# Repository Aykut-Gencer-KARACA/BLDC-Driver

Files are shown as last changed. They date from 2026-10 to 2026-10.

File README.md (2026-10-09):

<div align="center">

BLDC ESC — STM32F405 + DRV8300 sensörsüz six-step motor sürücü

<br/>









<br/><br/>

**Sıfırdan tasarlanmış bir fırçasız DC (BLDC) motor sürücüsü.**<br/>
Hall sensörü olmadan, boştaki fazın back-EMF sıfır geçişini okuyarak rotor konumunu tahmin eder.

<br/>

<a href="assets/pcb-render.mp4">
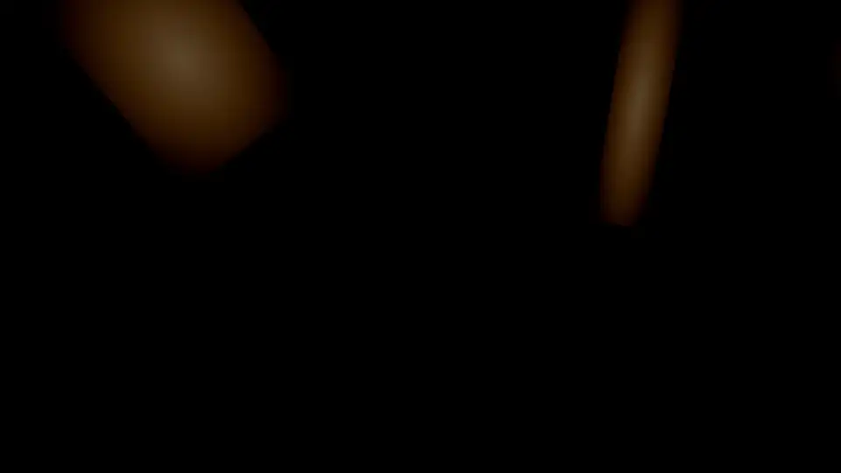
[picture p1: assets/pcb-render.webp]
PCB 3D render animasyonu
  
</a>

<sub>PCB'nin Blender'da hazırlanmış 3D render'ı · tam çözünürlüklü video için görsele tıklayın</sub>

</div>

<!--
  ────────────────────────────────────────────────────────────────────────────
  OYNATILABİLİR VİDEO (isteğe bağlı)
  GitHub, repodaki .mp4 dosyalarını README içinde oynatıcı olarak GÖSTERMEZ.
  Oynatıcı istiyorsanız:
    1) GitHub'da README.md'yi web editöründe açın (kalem simgesi).
    2) assets/pcb-render.mp4 dosyasını editöre sürükleyip bırakın.
    3) Oluşan https://github.com/user-attachments/assets/... satırını
       aşağıdaki "VIDEO_LINKI_BURAYA" satırının yerine koyun (tek başına, kendi satırında).
    4) Bu yorum bloğunu silebilirsiniz.
  ────────────────────────────────────────────────────────────────────────────
-->

<!-- VIDEO_LINKI_BURAYA -->



## İçindekiler

- [Genel bakış](#-genel-bakış)
- [Öne çıkanlar](#-öne-çıkanlar)
- [Sistem mimarisi](#-sistem-mimarisi)
- [Six-step komütasyon](#-six-step-komütasyon)
- [Donanım](#-donanım)
- [Tasarım hesapları](#-tasarım-hesapları)
- [Pin haritası](#-pin-haritası)
- [PCB](#-pcb)
- [Malzeme listesi](#-malzeme-listesi)
- [Depo yapısı](#-depo-yapısı)

## ◆ Genel bakış

Bu proje, bir **A2212 1000 KV** fırçasız motoru **3S LiPo** batarya ile sürmek için tasarlanmış bir ESC'dir (Electronic Speed Controller). Kart; güç girişi koruması, iki ayrı regülatör, 3 fazlı MOSFET köprüsü, faz başına bağımsız akım ölçümü, back-EMF algılama ve bir **STM32F405** mikrodenetleyiciyi tek bir PCB üzerinde topluyor.

Tasarımdaki her değer bir hesaba dayanıyor: MOSFET seçiminden bootstrap kondansatörüne, dead-time'dan ferrit bead bastırma oranına kadar kararların gerekçesi [Tasarım hesapları](#-tasarım-hesapları) bölümünde; tüm türetimler adım adım [Hesaplama Notları](Hesaplama%20Notları.pdf) dosyasında.

| Özellik | Değer |
|---|---|
| **Kontrol yöntemi** | Sensörsüz six-step (trapezoidal), back-EMF sıfır geçişi |
| **Giriş gerilimi** | 3S LiPo · 11.1 V nominal · 12.6 V maksimum |
| **Faz akımı** | 10 A sürekli · 12 A tepe (tasarım hedefi) |
| **Anahtarlama** | 30 kHz, center-aligned PWM, ~11.4 bit duty çözünürlüğü |
| **Dead-time** | 2 katman: TIM1 DTG ≈ 1 µs + DRV8300 sabit ≈ 215 ns (tipik) |
| **Akım ölçümü** | 3 × low-side şönt (10 mΩ) + 3 × INA180A1 (20 V/V), eşzamanlı örnekleme |
| **Hız ayarı** | Panel montaj 10 kΩ potansiyometre |
| **Programlama** | SWD (ST-Link V2) |

## ◆ Öne çıkanlar

<table>
<tr>
<td width="50%" valign="top">

**Katmanlı giriş koruması**<br/>
TVS diyot (SMBJ20A, 32.4 V clamp), 20 A SMD sigorta ve P-kanal ters polarite MOSFET. Hot-plug ve anahtarlama kaynaklı gerilim darbelerine karşı koruma.

</td>
<td width="50%" valign="top">

**Faz başına eşzamanlı akım ölçümü**<br/>
Üç şönt akımı üç ayrı ADC'ye dağıtıldı (ADC1/2/3) ve her birinde **Rank 1** kanalı. TIM1 CH4 tetiklediği anda üç faz aynı anda örnekleniyor, fazlar arası zaman kayması yok.

</td>
</tr>
<tr>
<td valign="top">

**Isıl hesabı yapılmış MOSFET seçimi**<br/>
DON100N04 (40 V, < 3.5 mΩ, **Q<sub>g</sub> ≈ 40 nC** @ 10 V). 10.5 A'de MOSFET başına ≈ 0.39 W (25 °C); sıcakken (4.46 mΩ) ≈ 0.49 W ve 40 °C ortamda T<sub>J</sub> ≈ 65 °C. Bu kartta tek MOSFET'in ısıl sınırı ≈ 22 A.

</td>
<td valign="top">

**Temiz analog besleme**<br/>
VDDA hattı ferrit bead + 100 nF + 1 µF ile buck ripple'ından ayrıldı. 500 kHz'de tahmini **30–60 kat (%97–98) bastırma**. ADC referansı ve CSA beslemesi aynı hattan: ölçüm oransal (ratiometric).

</td>
</tr>
<tr>
<td valign="top">

**Hesaplanmış bootstrap**<br/>
C<sub>BOOT,min</sub> ≈ 47 nF (TI'ın 1 V dalgalanma kuralı), seçilen 100 nF ile **~2× pay** ve ≈ 0.47 V dalgalanma. Üst kol kesintisiz açık kalamayacağı için %100 duty kullanılmıyor.

</td>
<td valign="top">

**Sanal nötr ile back-EMF algılama**<br/>
Faz başına 20 kΩ / 4.99 kΩ bölücü 12.6 V'u ≈ 2.52 V'a indiriyor; 3 × 20 kΩ + 1.65 kΩ'luk sanal nötr aynı ölçekte (sapma ≈ %0.7). Boştaki fazın nötrü kestiği an sıfır geçişi.

</td>
</tr>
</table>

## ◆ Sistem mimarisi

<p align="center">
  Sistem mimarisi blok diyagramı
</p>

Güç yolu soldan sağa akıyor: batarya, sırasıyla sigorta (F1), TVS diyodu (D1) ve ters polarite MOSFET'inden (Q7) geçip `V_BUS` barasına ulaşıyor. Bu baradan üç kol ayrılıyor:

- **TPS54202 buck** → 3.3 V (MCU, CSA'lar, potansiyometre) · 500 kHz senkron
- **BA00BC0WFP LDO** → 8 V GVDD (DRV8300 gate sürme beslemesi) · ≈ 5 mA tipik, en fazla ≈ 11 mA yük
- **3 faz köprü** → motor fazları A / B / C

STM32, TIM1'in 6 tamamlayıcı PWM çıkışıyla DRV8300'ü sürüyor; DRV8300 de bootstrap üzerinden üst kol N-kanal MOSFET'lerin gate'lerini bara geriliminin üstüne taşıyor.

## ◆ Six-step komütasyon

<p align="center">
  Six-step komütasyon animasyonu
</p>

Her elektriksel periyot altı adıma bölünüyor. Her adımda **iki faz aktif** (biri üst koldan PWM'leniyor, diğeri alt koldan sürekli iletimde), **üçüncü faz boşta** kalıyor. Boştaki fazın back-EMF'i sanal nötr seviyesini kestiği anda (sıfır geçişi) rotorun konumu biliniyor ve bir sonraki adıma geçiş zamanlanıyor.

| Adım | 1 | 2 | 3 | 4 | 5 | 6 |
|:--|:-:|:-:|:-:|:-:|:-:|:-:|
| **Üst kol (PWM)** | A | A | B | B | C | C |
| **Alt kol (açık)** | B | C | C | A | A | B |
| **Boşta (BEMF ölçümü)** | C | B | A | C | B | A |

> [!NOTE]
> Motor dururken back-EMF olmadığı için sensörsüz kontrolde **açık döngü başlatma** (open-loop ramp) gerekiyor. Motor yeterli hıza ulaşıp BEMF okunabilir hale geldiğinde kapalı döngüye geçiliyor.

## ◆ Donanım

<details open>
<summary><b>Güç katı</b></summary>
<br/>

| Blok | Parça | Not |
|---|---|---|
| Yarım köprü MOSFET'leri | 6 × **DON100N04** (DFN-8) | 40 V · < 3.5 mΩ · Q<sub>g</sub> ≈ 40 nC · gövde diyodu yeterli, harici Schottky yok |
| Gate dirençleri | 6 × 15 Ω | TI referans tasarımı ve bağımsız hesapla doğrulandı |
| Gate pull-down | 6 × 10 kΩ | Self turn-on koruması |
| Faz kondansatörleri | Faz başına 100 µF + 1 µF + 100 nF | Bulk + decoupling |

</details>

<details>
<summary><b>Gate sürücü — DRV8300</b></summary>
<br/>

- DT pini boşta (ya da GND'de): dahili dead-time ≈ 215 ns (tipik, datasheet)
- Bootstrap: 100 nF, entegre bootstrap diyodu
- GVDD: 8 V LDO çıkışı
- nFAULT çıkışı yok → donanımsal aşırı akım kesmesi (BKIN) yok; akım, şönt + INA180 zinciriyle ölçülüyor

</details>

<details>
<summary><b>Akım ölçümü</b></summary>
<br/>

- 3 × **10 mΩ / 3 W** şönt (2512), alt kol altında (low-side)
- 3 × **INA180A1** (20 V/V) — 12 A'de 2.4 V çıkış
- Çıkışta 100 Ω + 22 nF RC filtre (f<sub>c</sub> ≈ 72 kHz)
- 12-bit ADC ile çözünürlük ≈ **4 mA / LSB**

</details>

<details>
<summary><b>Back-EMF algılama</b></summary>
<br/>

- Faz başına bölücü: 20 kΩ / 4.99 kΩ → 12.6 V faz geriliminde **≈ 2.52 V** ADC girişi
- Sanal nötr: 3 × 20 kΩ yıldız + 1.65 kΩ (R<sub>n</sub> = R<sub>alt</sub>/3) → faz bölücüleriyle aynı ölçek
- Tüm dirençler ±%1; ölçek sapması ≈ %0.7

</details>

<details>
<summary><b>Mikrodenetleyici — STM32F405RGT6</b></summary>
<br/>

- Cortex-M4F · 168 MHz · 1 MB Flash · 192 KB RAM · FPU
- 8 MHz HSE kristal, 2 × 30 pF yük kondansatörü (C<sub>L</sub> = 20 pF)
- VCAP1/2: 2 × 2.2 µF X5R
- 4 × VDD'ye ayrı 100 nF, VBAT → 3.3 V + 100 nF
- NRST: 100 nF + tact switch · BOOT0: 10 kΩ ile GND
- SWD: 4 pinlik 2.54 mm header (3.3 V, SWDIO, SWCLK, GND)

</details>

<details>
<summary><b>Göstergeler (LED)</b></summary>
<br/>

| LED | Görev | Sürüş | Akım |
|---|---|---|---|
| LED1 | Güç göstergesi | 3.3 V → R38 (200 Ω) → LED1 → GND | ≈ 6.5 mA |
| LED2 | SWD aktivite göstergesi | 3.3 V → R39 (200 Ω) → LED2 → Q8 (MMBT5551, low-side) · baz SWCLK'ten R40 (10 kΩ) ile | ≈ 6.5 mA |

- LED2, debugger bağlıyken SWCLK üzerindeki trafikle yanıp söner; MCU pini harcamaz.
- Q8'in baz akımı ≈ 0.26 mA — SWCLK hattını anlamlı ölçüde yüklemez.

</details>

## ◆ Tasarım hesapları

<details>
<summary><b>MOSFET seçimi</b></summary>
<br/>

$$V_{DS} \geq 2 \times V_{\text{bara,max}} = 2 \times 12.6\text{ V} = 25.2\text{ V} \quad\Rightarrow\quad 40\text{ V sınıfı}$$

$$I_D \geq 3 \times I_{\text{çalışma}} = 3 \times 10\text{ A} = 30\text{ A} \quad\Rightarrow\quad \text{DON100N04: 100 A}$$

İletim kaybı, 25 °C'de $R_{DS(on)} \leq 3.5\text{ m}\Omega$ ile:

$$P = I^2 \times R_{DS(on)} = 10.5^2 \times 0.0035 \approx 0.39\text{ W}$$

Asıl karar ısıl hesapla verilir. Sıcakken (150 °C) direnç ≈ 4.46 mΩ, R<sub>θJA</sub> = 50 °C/W ve T<sub>A</sub> = 40 °C ile:

$$P = 10.5^2 \times 0.00446 \approx 0.49\text{ W} \quad\Rightarrow\quad T_J = T_A + P \times R_{\theta JA} = 40 + 0.49 \times 50 \approx 65\text{ °C}$$

$$I_{max} = \sqrt{\frac{(150 - 40)/50}{0.00446}} = \sqrt{\frac{2.2\text{ W}}{0.00446\ \Omega}} \approx 22\text{ A}$$

Yani bu kartta tek bir MOSFET'in sürekli taşıyabileceği akım datasheet'teki 100 A değil, yaklaşık 22 A'dir; 10.5 A çalışma noktası bunun çok altındadır.

</details>

<details>
<summary><b>Bootstrap kondansatörü</b></summary>
<br/>

$$\Delta V_{BST} = V_{GVDD} - V_{BOOTD} - V_{BSTUV} = 8 - 0.85 - 4.5 = 2.65\text{ V}$$

$$Q_{tot} = Q_g + \frac{I_{LBS,TRAN}}{f_{sw}} = 40\text{ nC} + \frac{220\ \mu\text{A}}{30\text{ kHz}} \approx 47\text{ nC}$$

TI, kondansatör üzerindeki çevrim başına dalgalanmanın 1 V'u geçmemesini öneriyor:

$$C_{BOOT,min} = \frac{Q_{tot}}{1\text{ V}} \approx 47\text{ nF} \quad\Rightarrow\quad 100\text{ nF seçildi (yaklaşık 2 kat pay)}$$

100 nF ile dalgalanma $47\text{ nC} / 100\text{ nF} \approx 0.47\text{ V}$, yani 2.65 V'luk sınırın çok altında. GVDD tarafında kural $C_{GVDD} \geq 10 \times C_{BOOT} = 1\ \mu\text{F}$; datasheet GVDD pininde ayrıca en az 10 µF istiyor (C43 = 10 µF, C40 = 1 µF, C42 = 100 nF).

Üst kolun kesintisiz açık kalabileceği süre, 150 µA'lik statik sızıntıyla $2.65\text{ V} \times 100\text{ nF} / 150\ \mu\text{A} \approx 1.8\text{ ms}$ (≈ 53 PWM periyodu). Bu yüzden duty %100'e çıkarılmamalı ve motor başlamadan önce alt kollar açılarak bootstrap kondansatörleri şarj edilmeli.

</details>

<details>
<summary><b>Gate direnci ve anahtarlama süresi</b></summary>
<br/>

$$I_{\text{tepe}} \approx \frac{V_{GVDD}}{R_g} = \frac{8\text{ V}}{15\ \Omega} \approx 0.5\text{ A}$$

Sürücünün kendi iç direnci eklendiği için gerçek tepe akım bunun biraz altında kalır ve DRV8300'ün 0.75 A'lik (tipik) açma akımı sınırının içindedir. 15 Ω daha yumuşak anahtarlama (düşük di/dt, düşük aşım) ile daha hızlı anahtarlama arasında bir dengedir.

Sürücünün işi: 40 nC'luk gate'i bir GPIO'nun 25 mA'iyle doldurmak $t \approx Q_g / I = 40\text{ nC} / 25\text{ mA} \approx 1.6\ \mu\text{s}$ sürerdi; DRV8300'ün 0.75 A'iyle aynı süre ≈ 53 ns'dir.

</details>

<details>
<summary><b>PWM çözünürlüğü</b></summary>
<br/>

Center-aligned modda sayaç yukarı-aşağı saydığı için:

$$ARR = \frac{f_{timer}}{2 \times f_{PWM}} = \frac{168\text{ MHz}}{2 \times 30\text{ kHz}} = 2800 \;\;(\approx 11.4\text{ bit})$$

</details>

<details>
<summary><b>GVDD akım bütçesi ve LDO</b></summary>
<br/>

Six-step'te her an yalnızca PWM uygulanan koldaki iki MOSFET anahtarlanır:

$$I_{\text{gate}} = 2 \times Q_g \times f_{sw} = 2 \times 40\text{ nC} \times 30\text{ kHz} = 2.4\text{ mA}$$

(Altı MOSFET'in birden anahtarlandığı en kötü durumda 7.2 mA.) Üst kol gate yükü bootstrap kondansatöründen akar ama her çevrimde yine GVDD'den yeniden alınır, bu yüzden bütçeye dahildir.

| Kalem | Tipik | En fazla |
|---|---|---|
| DRV8300 kendi tüketimi | 0.83 mA | 1.4 mA |
| Gate'leri doldurmak | 2.4 mA | 7.2 mA |
| Bootstrap tüketimi (3 kanal) | 0.32 mA | 0.66 mA |
| Gate pull-down'lar (2 MOSFET iletimde, 8 V / 10 kΩ) | 1.6 mA | 1.6 mA |
| **Toplam** | **≈ 5.2 mA** | **≈ 10.9 mA** |

LDO çıkışı: $V_O = 1.25 \times \frac{30k + 162k}{30k} = 8\text{ V}$

LDO kaybı: $P = (V_{in} - V_{out}) \times I = (12.6 - 8) \times 5.2\text{ mA} \approx 24\text{ mW}$ (üst sınır: $4.6\text{ V} \times 10.9\text{ mA} \approx 50\text{ mW}$).

</details>

<details>
<summary><b>3.3 V buck regülatörü</b></summary>
<br/>

| Yük | Akım |
|---|---|
| STM32F405 (168 MHz) | ~150 mA |
| 3 × INA180 | 1 mA |
| LDO CTL pini | 0.13 mA |
| Potansiyometre | ~1 mA |
| LED'ler (LED1 + LED2, her biri ≈ 6.5 mA) | ~13 mA |
| **Toplam** | **~165 mA** → TPS54202 2 A (≈ 12× akım payı, 28 V / 12.6 V ≈ 2.2× gerilim payı) |

Buck yerine LDO kullanılsaydı kayıp $(12.6 - 3.3) \times 0.165 \approx 1.5\text{ W}$ olurdu; 8 V'luk LDO'da ise akım yalnızca birkaç mA olduğu için bu sorun yok.

$V_{OUT} = 0.596 \times \frac{100k + 22.1k}{22.1k} \approx 3.29\text{ V}$ · L = 10 µH · C<sub>OUT</sub> = 2 × 22 µF · 56 pF feedforward.

500 kHz anahtarlama frekansı CSA filtresinin kesim frekansından (≈ 72 kHz) ≈ 7 kat uzakta; filtre bu gürültüyü ≈ 7 kat (−17 dB) azaltır.

</details>

<details>
<summary><b>Akım ölçüm zinciri</b></summary>
<br/>

$$V_{out} = I \times R_{\text{şönt}} \times G = 12\text{ A} \times 10\text{ m}\Omega \times 20 = 2.4\text{ V}$$

$$1\text{ LSB} = \frac{3.3\text{ V}}{4096} \approx 0.806\text{ mV} \quad\Rightarrow\quad \approx 4\text{ mA / LSB}$$

Çıkış 3.3 V'ta doyduğu için ölçülebilecek en büyük akım $3.3\text{ V} / 0.2\text{ V/A} \approx 16.5\text{ A}$; bu değer çalışma akımının üstünde, 22 A'lik ısıl sınırın altındadır ve doymuş çıkış zaten aşırı akım demektir.

Şönt low-side'da olduğu için common-mode gerilim 0–120 mV aralığında (12 A'de 120 mV) kalıyor; high-side ölçümün yüksek common-mode salınımıyla uğraşmak gerekmiyor.

</details>

## ◆ Pin haritası

<table>
<tr>
<td valign="top">

**TIM1 → DRV8300**

| Kanal | Pin | Giriş |
|---|---|---|
| CH1 | PA8 | INHA |
| CH2 | PA9 | INHB |
| CH3 | PA10 | INHC |
| CH1N | PB13 | INLA |
| CH2N | PB14 | INLB |
| CH3N | PB15 | INLC |
| CH4 | dahili | ADC tetikleme |

</td>
<td valign="top">

**ADC kanalları**

| Sinyal | ADC | Rank | Pin |
|---|---|---|---|
| Şönt A | ADC1 | 1 | PA0 |
| BEMF A | ADC1 | 2 | PA1 |
| Şönt B | ADC2 | 1 | PA2 |
| BEMF B | ADC2 | 2 | PA3 |
| Şönt C | ADC3 | 1 | PC0 |
| BEMF C | ADC3 | 2 | PC1 |
| Sanal nötr | ADC3 | 3 | PC2 |
| Potansiyometre | ADC3 | 4 | PC3 |

</td>
</tr>
</table>

Altı PWM sinyali LQFP-64'ün aynı kenarında (pin 33–48) toplandı; DRV8300 bu kenara yerleştirilerek hatlar kısa ve paralel tutuluyor, BEMF/CSA hatlarından uzaklaştırılıyor. 64 pinin 33'ü kullanılıyor; USART3/USART6 (telemetri) ve TIM1_BKIN pinleri boşta.

## ◆ PCB

<table>
<tr>
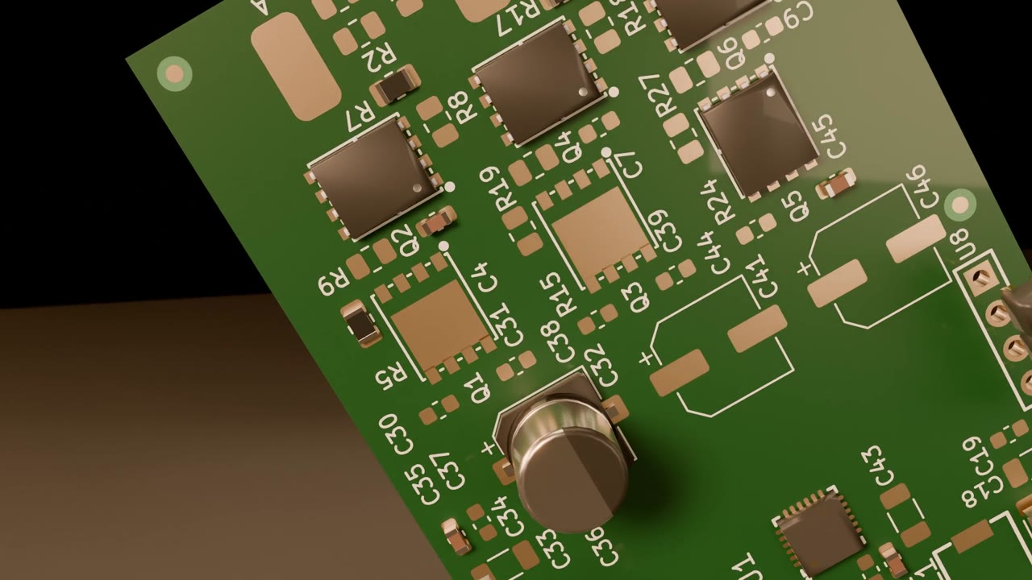
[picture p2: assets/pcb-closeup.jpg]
Güç katı yakın çekim
<td width="33%"></td>
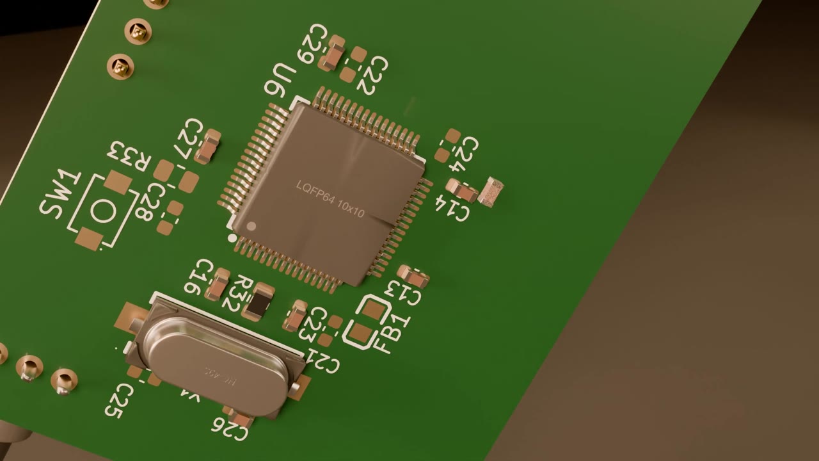
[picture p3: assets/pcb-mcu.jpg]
STM32F405 ve kristal
<td width="33%"></td>
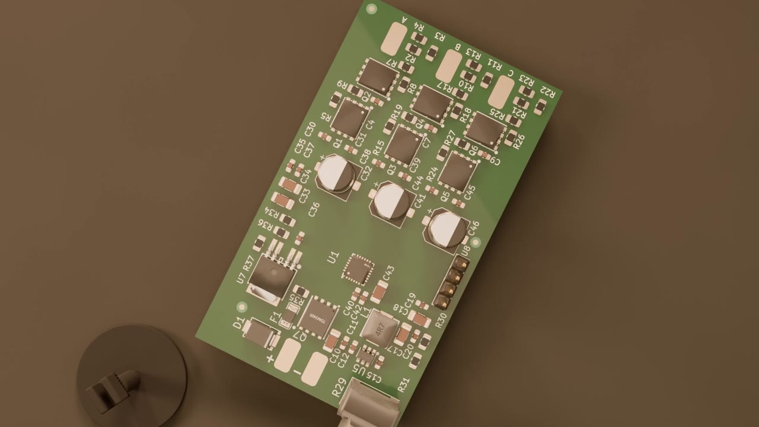
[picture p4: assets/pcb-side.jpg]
Yan görünüm
<td width="33%"></td>
</tr>
<tr>
<td align="center"><sub>Güç katı · MOSFET'ler ve bara kondansatörleri</sub></td>
<td align="center"><sub>STM32F405 · HSE kristal · reset butonu</sub></td>
<td align="center"><sub>Potansiyometre ve SWD header</sub></td>
</tr>
</table>

## ◆ Malzeme listesi

<details>
<summary><b>Ana bileşenler</b> (tam liste için tıklayın)</summary>
<br/>

| Ref | Açıklama | Parça | Adet | Kılıf |
|---|---|---|:-:|---|
| U1 | Gate sürücü | DRV8300DRGER | 1 | QFN-24 |
| U2–U4 | Akım ölçüm yükselticisi | INA180A1IDBVR | 3 | SOT-23-5 |
| U5 | Buck 3.3 V | TPS54202DDCR | 1 | SOT-23-6 |
| U6 | MCU | STM32F405RGT6 | 1 | LQFP-64 |
| U7 | LDO 8 V | BA00BC0WFP-E2 | 1 | TO-252-5 |
| U8 | SWD header | 2.54 mm 1×4P | 1 | THT |
| Q1–Q6 | Köprü MOSFET'leri | DON100N04 | 6 | DFN-8 |
| Q7 | Ters polarite | HSBA4119 | 1 | DFN-8 |
| F1 | Sigorta 20 A / 32 VDC | BSMD1206C-2200T | 1 | 1206 |
| D1 | TVS | SMBJ20A | 1 | SMB |
| L1 | Buck bobini 10 µH | SLO0520H100MTT | 1 | SMD |
| FB1 | Ferrit bead (VDDA) | MMZ2012Y202BTD25 | 1 | 0805 |
| X1 | Kristal 8 MHz | X49SM8MSD2SC | 1 | HC-49S-SMD |
| R12, R20, R28 | Şönt 10 mΩ / 3 W ±%1 | Milliohm HoYLR2512-3W-10mR-1% | 3 | 2512 |
| R29 | Hız potansiyometresi 10 kΩ | ALPS RK09Y11L0001 | 1 | THT |
| SW1 | Reset butonu | TS342A2P | 1 | SMD |
| LED1, LED2 | Gösterge LED'i, kırmızı (güç · SWD aktivite) | YLED0805R | 2 | 0805 |
| Q8 | LED2 sürücü NPN | MMBT5551 | 1 | SOT-23 |
| R38, R39 | LED akım direnci 200 Ω | FRC0805F2000TS | 2 | 0805 |
| R40 | Q8 baz direnci 10 kΩ | FRC0805F1002TS | 1 | 0805 |
| J1, J2 | Batarya girişi (lehim pad) | — | 2 | SMD pad 3×6 mm |
| J3–J5 | Motor fazları A/B/C (lehim pad) | — | 3 | SMD pad 3×6 mm |

**Kondansatörler (46):** 20 × 100 nF · 9 × 1 µF · 4 × 10 µF · 3 × 100 µF elektrolitik · 2 × 22 µF · 2 × 2.2 µF · 3 × 22 nF · 2 × 30 pF · 1 × 56 pF.

**Dirençler (0805, tabloda olmayanlar — 33):** 8 × 10 kΩ (gate pull-down, BOOT0, Q7 gate) · 6 × 20 kΩ %1 · 6 × 15 Ω · 3 × 4.99 kΩ %1 · 3 × 100 Ω · 1.65 kΩ %1 · 100 kΩ %1 · 22.1 kΩ %1 · 162 kΩ · 30 kΩ · 0.5 Ω · 0 Ω.

**Sistem:** A2212 1000 KV motor · Leopard Power 1800 mAh 3S 25C LiPo · iMAX B6AC şarj cihazı · ST-Link V2.

</details>

## ◆ Depo yapısı

```text
BLDC-Driver/
├─ KiCad Project/         KiCad projesi (güncel sürüm: RevC)
│  ├─ BLDCdriver.kicad_pro / _sch / _pcb / _dru
│  ├─ BLDCdriver.pdf      Şematik çıktısı
│  ├─ EasyEDA.kicad_sym   Sembol kütüphanesi
│  ├─ EasyEDA.pretty/     Footprint'ler
│  └─ EasyEDA.3dshapes/   3D modeller
├─ assets/                README görselleri, PCB render'ı
├─ Hesaplama Notları.pdf  Tasarım hesapları
└─ README.md
```

Projeyi açmak için KiCad'de `KiCad Project/BLDCdriver.kicad_pro` dosyasını açın. Kütüphane yolları göreli olduğundan klasörü olduğu gibi klonlamak yeterli. Revizyon bilgisi şemanın ve PCB'nin başlık bloğundadır.

<br/>

<div align="center">

<br/>
<sub>STM32F405 · DRV8300 · INA180 · TPS54202 · Blender</sub>
</div>

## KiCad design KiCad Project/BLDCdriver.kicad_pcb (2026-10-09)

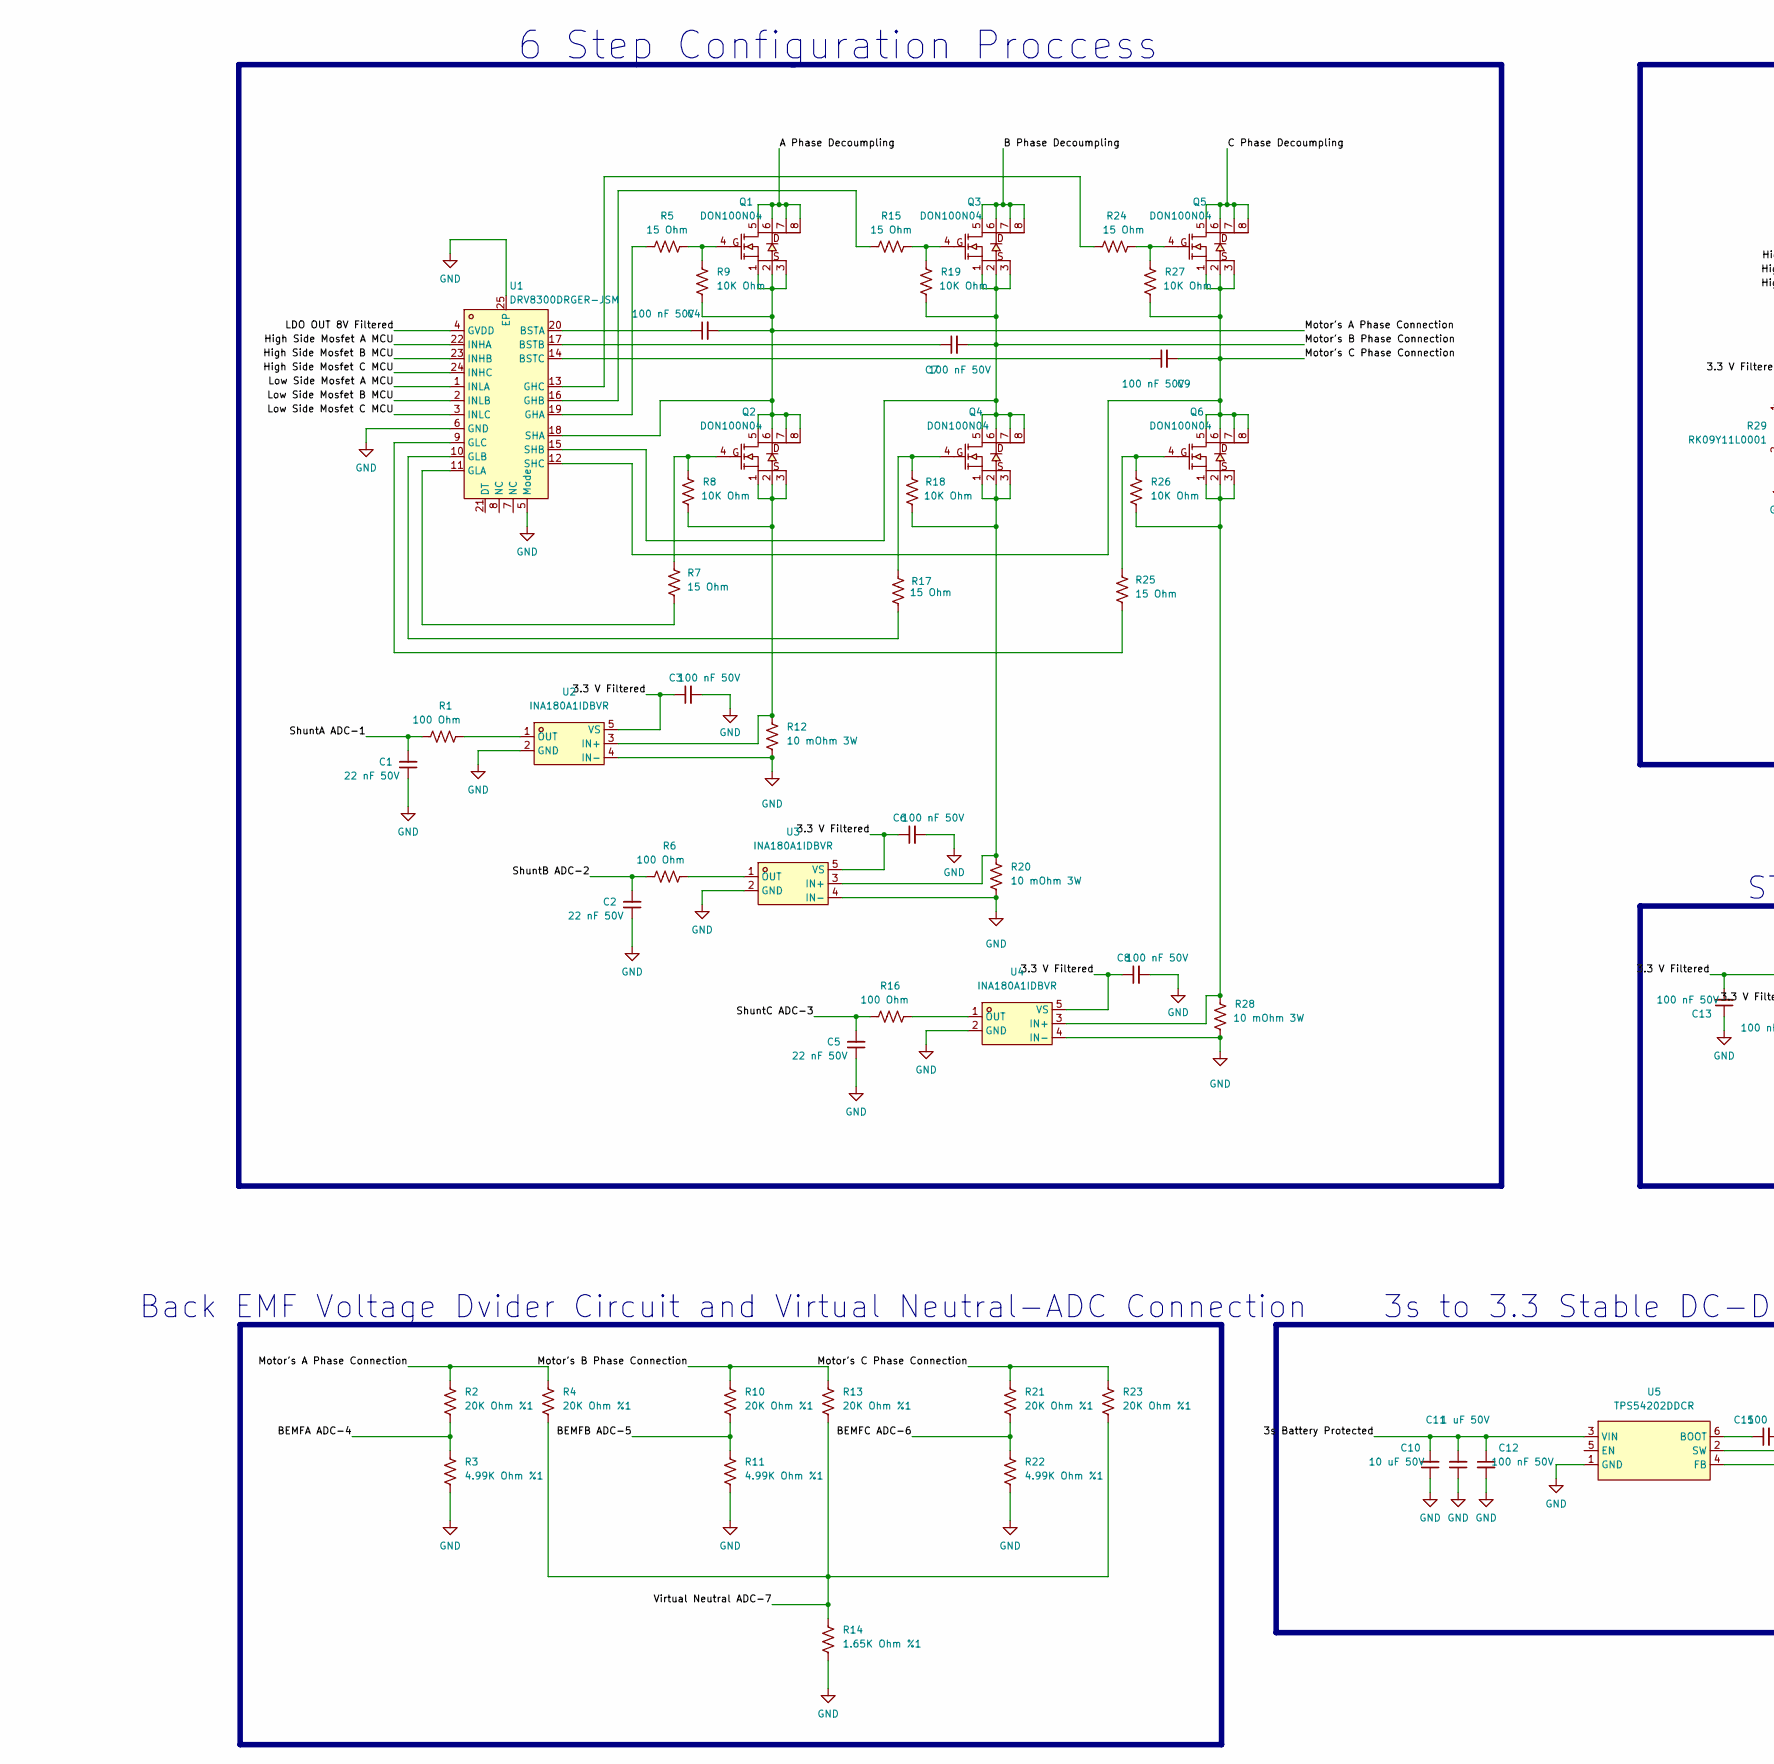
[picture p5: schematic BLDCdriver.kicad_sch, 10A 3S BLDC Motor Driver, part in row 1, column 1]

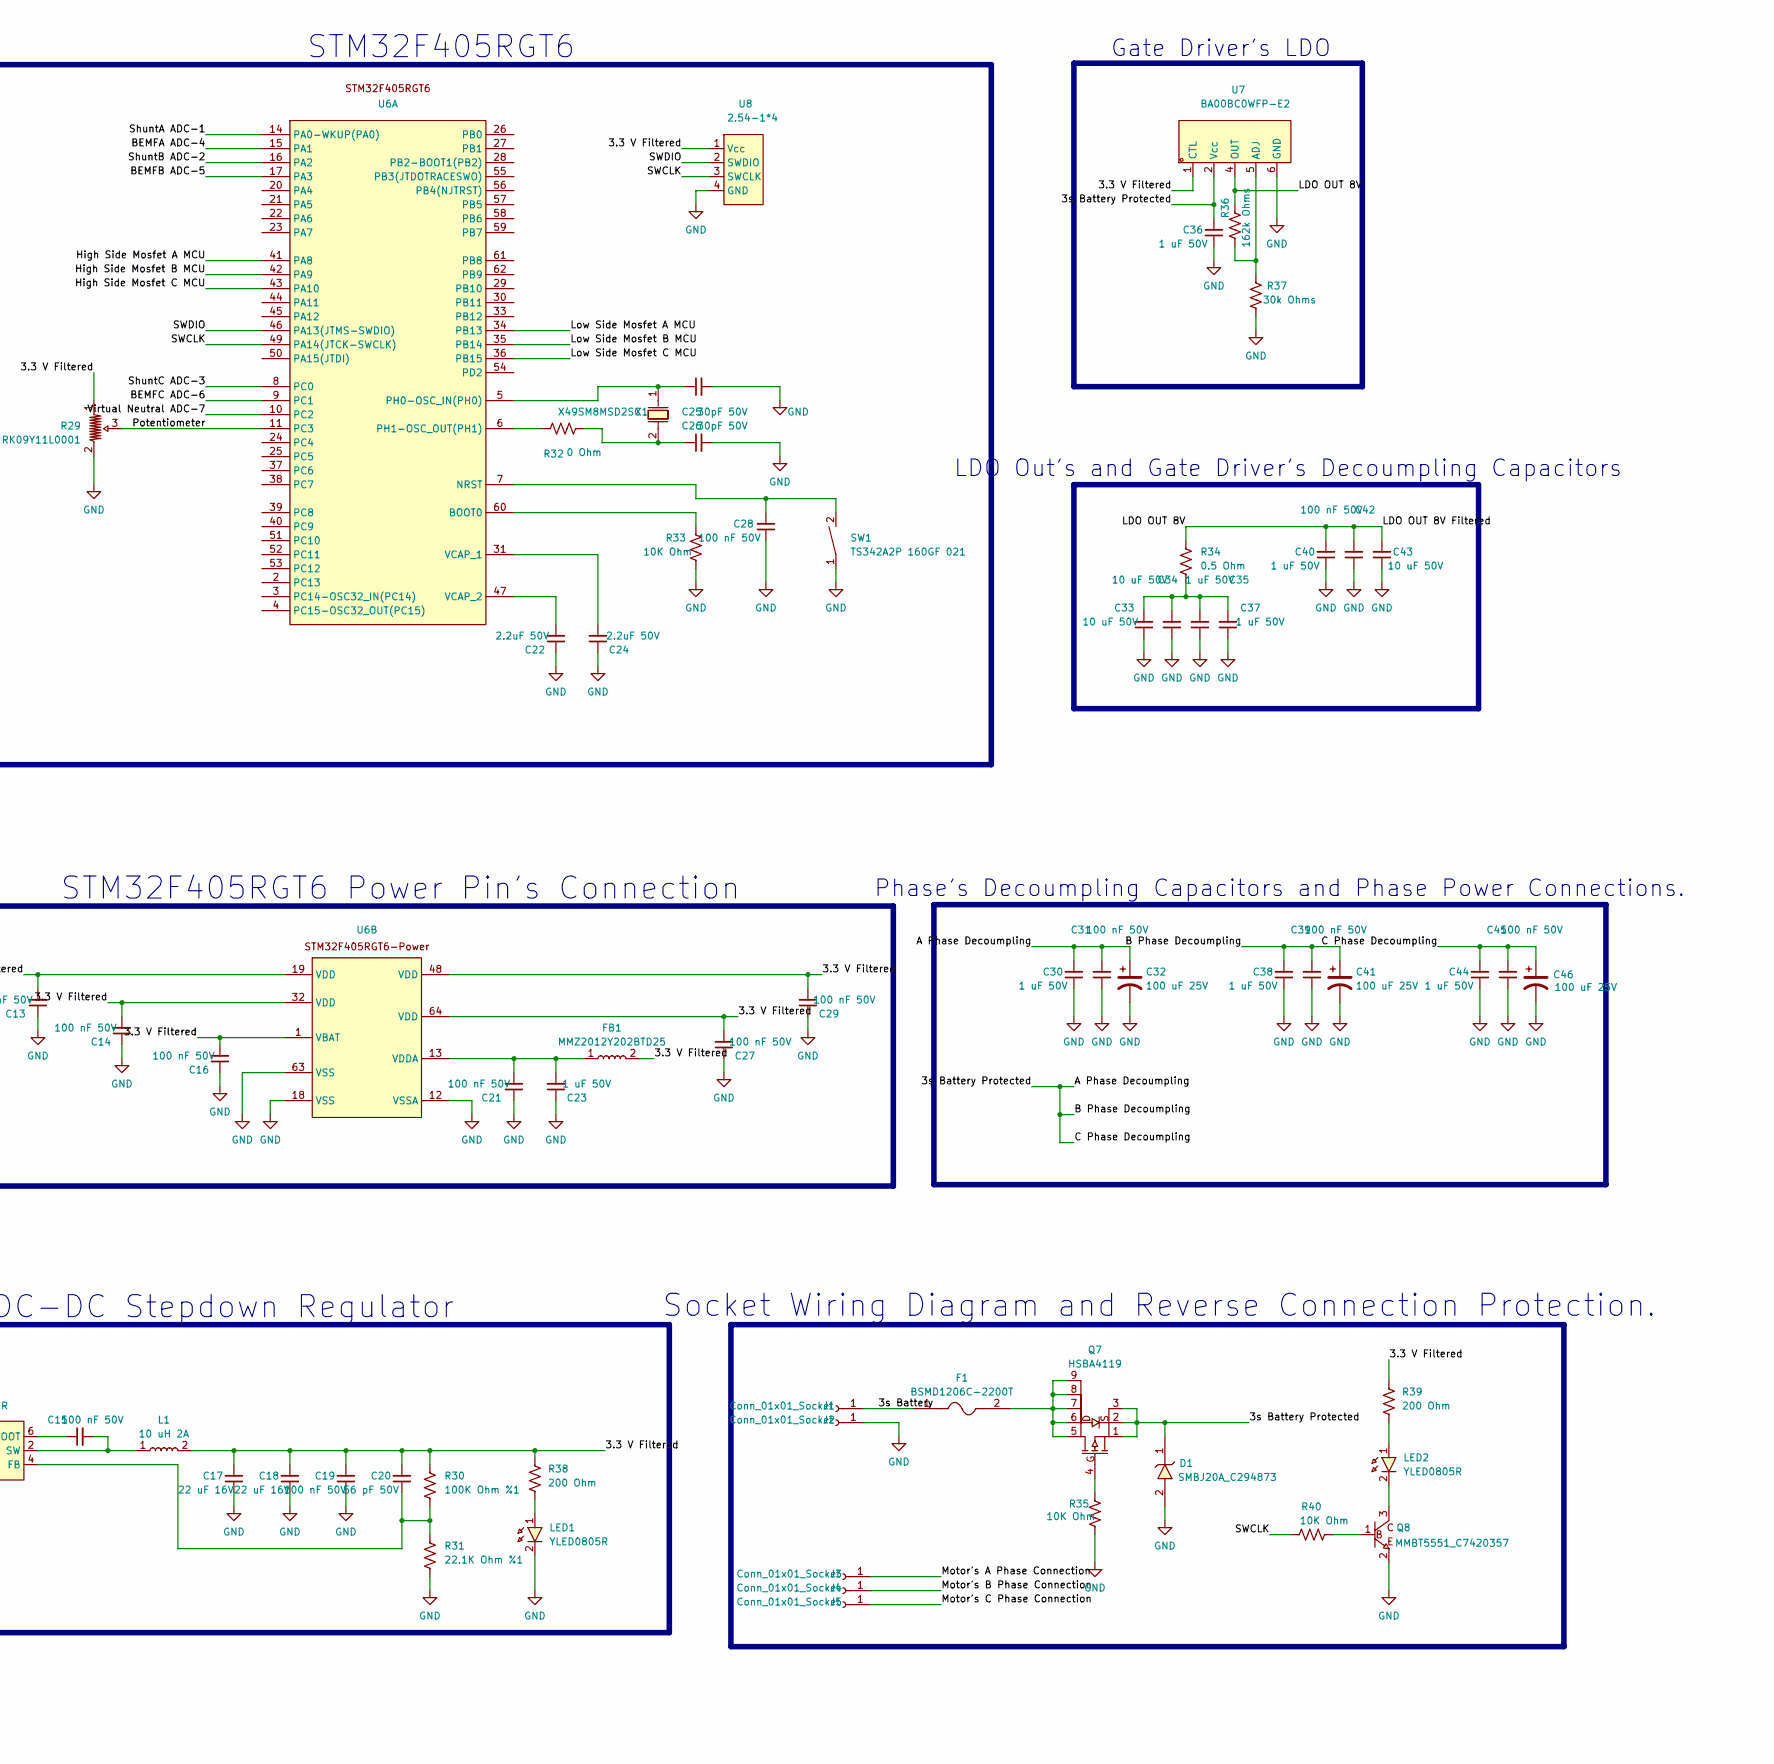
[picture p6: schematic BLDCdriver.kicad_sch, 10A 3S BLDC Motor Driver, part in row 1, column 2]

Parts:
C1, C2, C5: 22 nF 50V; C_0603_1608Metric; LCSC Part C21122
C3, C4, C6, C7, C8, C9, C12, C13, C14, C15, C16, C19, C21, C27, C28, C29, C31, C39, C42, C45: 100 nF 50V; C_0603_1608Metric; LCSC Part C14663
C10, C33, C34, C43: 10 uF 50V; C_1206_3216Metric; LCSC Part C13585
C11, C23, C30, C35, C36, C37, C38, C40, C44: 1 uF 50V; C_0603_1608Metric; LCSC Part C5199872
C17, C18: 22 uF 16V; C_1206_3216Metric; LCSC Part C5448976
C20: 56 pF 50V; C_0603_1608Metric; LCSC Part C107053
C22, C24: 2.2uF 50V; C_0603_1608Metric; LCSC Part C913904
C25, C26: 30pF 50V; C_0603_1608Metric; LCSC Part C113797
C32, C41, C46: 100 uF 25V; CP_Elec_6.3x7.7; LCSC Part C46528102
D1: SMBJ20A_C294873; SMB_L4.6-W3.6-LS5.3-RD; LCSC Part C294873
F1: BSMD1206C-2200T; F1206; LCSC Part C41398512
FB1: MMZ2012Y202BTD25; L0805; LCSC Part C360718
J1, J2, J3, J4, J5: Conn_01x01_Socket; SolderWirePad_1x01_SMD_3x6mm
L1: 10 uH 2A; IND-SMD_L5.4-W5.1; LCSC Part C325986
LED1, LED2: YLED0805R; LED0805-R-RD_RED; LCSC Part C19171391
Q1, Q2, Q3, Q4, Q5, Q6: DON100N04; DFN-8_L5.8-W4.9-P1.27-LS6.1-BL-2; LCSC Part C41430596
Q7: HSBA4119; DFN-8_L5.7-W5.1-P1.27-LS6.1-BL; LCSC Part C22359242
Q8: MMBT5551_C7420357; SOT-23-3_L2.9-W1.3-P1.90-LS2.4-BR; LCSC Part C7420357
R1, R6, R16: 100 Ohm; R_0805_2012Metric; LCSC Part C17408
R2, R4, R10, R13, R21, R23: 20K Ohm %1; R_0805_2012Metric; LCSC Part C2907240
R3, R11, R22: 4.99K Ohm %1; R_0805_2012Metric; LCSC Part C2933454
R5, R7, R15, R17, R24, R25: 15 Ohm; R_0805_2012Metric; LCSC Part C17480
R8, R9, R18, R19, R26, R27, R33, R35, R40: 10K Ohm; R_0805_2012Metric; LCSC Part C2907219
R12, R20, R28: 10 mOhm 3W; R_2512_6332Metric; LCSC Part C5375464
R14: 1.65K Ohm %1; R_0805_2012Metric; LCSC Part C2933334
R29: RK09Y11L0001; RES-ADJ-TH_RK09Y11L0001; LCSC Part C470717
R30: 100K Ohm %1; R_0805_2012Metric; LCSC Part C149504
R31: 22.1K Ohm %1; R_0805_2012Metric; LCSC Part C17552
R32: 0 Ohm; R_0805_2012Metric; LCSC Part C17477
R34: 0.5 Ohm; R_0805_2012Metric; LCSC Part C2934267
R36: 162k Ohms; R_0805_2012Metric; LCSC Part C17486
R37: 30k Ohms; R_0805_2012Metric; LCSC Part C2907255
R38, R39: 200 Ohm; R_0805_2012Metric; LCSC Part C2907239
SW1: TS342A2P 160GF 021; KEY-SMD_L3.9-W3.0-LS5.0; LCSC Part C5373431
U1: DRV8300DRGER-JSM; QFN-24_L4.0-W4.0-P0.50-BL-EP2.7; LCSC Part C3655801
U2, U3, U4: INA180A1IDBVR; SOT-23-5_L3.0-W1.7-P0.95-LS2.8-BR; LCSC Part C122228
U5: TPS54202DDCR; SOT-23-6_L2.9-W1.6-P0.95-LS2.8-BL; LCSC Part C191884
U6: LQFP-64_L10.0-W10.0-P0.50-LS12.0-BL; LCSC Part C15742
U7: BA00BC0WFP-E2; TO-252-5_L6.5-W5.5-P1.30-LS10.0-BR; LCSC Part C308578
U8: 2.54-1*4; HDR-TH_4P-P2.54-V-M-1; LCSC Part C5116483
X1: X49SM8MSD2SC; CRYSTAL-SMD_L11.5-W4.8-LS12.7; LCSC Part C12674

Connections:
/3.3 V Filtered: C3.1, C6.1, C8.1, C13.2, C14.2, C16.2, C17.2, C18.2, C19.2, C20.2, C27.2, C29.2, FB1.2, L1.2, R29.1, R30.1, R38.1, R39.1, U2.5 (VS), U3.5 (VS), U4.5 (VS), U6.1 (VBAT), U6.19 (VDD), U6.32 (VDD), U6.48 (VDD), U6.64 (VDD), U7.1 (CTL), U8.1 (Vcc)
/3s Battery: F1.1, J1.1 (Pin_1_1)
/3s Battery Protected: C10.2, C11.2, C12.1, C30.2, C31.2, C32.1, C36.2, C38.2, C39.2, C41.1, C44.2, C45.2, C46.1, D1.1, Q1.5, Q1.6, Q1.7, Q1.8, Q3.5, Q3.6, Q3.7, Q3.8, Q5.5, Q5.6, Q5.7, Q5.8, Q7.1, Q7.2, Q7.3, U5.3 (VIN), U7.2 (Vcc)
/BEMFA ADC-4: R2.2, R3.1, U6.15 (PA1)
/BEMFB ADC-5: R10.2, R11.1, U6.17 (PA3)
/BEMFC ADC-6: R21.2, R22.1, U6.9 (PC1)
/High Side Mosfet A MCU: U1.22 (INHA), U6.41 (PA8)
/High Side Mosfet B MCU: U1.23 (INHB), U6.42 (PA9)
/High Side Mosfet C MCU: U1.24 (INHC), U6.43 (PA10)
/LDO OUT 8V: C40.2, C42.2, C43.2, R34.1, R36.1, U1.4 (GVDD), U7.4 (OUT)
/Low Side Mosfet A MCU: U1.1 (INLA), U6.34 (PB13)
/Low Side Mosfet B MCU: U1.2 (INLB), U6.35 (PB14)
/Low Side Mosfet C MCU: U1.3 (INLC), U6.36 (PB15)
/Motor's A Phase Connection: C4.2, J3.1 (Pin_1_1), Q1.1, Q1.2, Q1.3, Q2.5, Q2.6, Q2.7, Q2.8, R2.1, R4.1, R9.2, U1.18 (SHA)
/Motor's B Phase Connection: C7.2, J4.1 (Pin_1_1), Q3.1, Q3.2, Q3.3, Q4.5, Q4.6, Q4.7, Q4.8, R10.1, R13.1, R19.2, U1.15 (SHB)
/Motor's C Phase Connection: C9.2, J5.1 (Pin_1_1), Q5.1, Q5.2, Q5.3, Q6.5, Q6.6, Q6.7, Q6.8, R21.1, R23.1, R27.2, U1.12 (SHC)
/Potentiometer: R29.3, U6.11 (PC3)
/SWCLK: R40.1, U6.49 (PA14(JTCK-SWCLK)), U8.3 (SWCLK)
/SWDIO: U6.46 (PA13(JTMS-SWDIO)), U8.2 (SWDIO)
/ShuntA ADC-1: C1.2, R1.1, U6.14 (PA0-WKUP(PA0))
/ShuntB ADC-2: C2.2, R6.1, U6.16 (PA2)
/ShuntC ADC-3: C5.2, R16.1, U6.8 (PC0)
/Virtual Neutral ADC-7: R4.2, R13.2, R14.1, R23.2, U6.10 (PC2)
GND: C1.1, C2.1, C3.2, C5.1, C6.2, C8.2, C10.1, C11.1, C12.2, C13.1, C14.1, C16.1, C17.1, C18.1, C19.1, C21.1, C22.1, C23.1, C24.1, C25.2, C26.2, C27.1, C28.1, C29.1, C30.1, C31.1, C32.2, C33.1, C34.1, C35.1, C36.1, C37.1, C38.1, C39.1, C40.1, C41.2, C42.1, C43.1, C44.1, C45.1, C46.2, D1.2, J2.1 (Pin_1_1), LED1.2, Q8.2, R3.2, R11.2, R12.2, R14.2, R20.2, R22.2, R28.2, R29.2, R31.2, R33.2, R35.2, R37.1, SW1.1, U1.5 (Mode), U1.6 (GND), U1.25 (EP), U2.2 (GND), U2.4 (IN-), U3.2 (GND), U3.4 (IN-), U4.2 (GND), U4.4 (IN-), U5.1 (GND), U6.12 (VSSA), U6.18 (VSS), U6.63 (VSS), U7.6 (GND), U8.4 (GND)
unnamed: C26.1, R32.2, X1.2
unnamed: C33.2, C34.2, C35.2, C37.2, R34.2
unnamed: F1.2, Q7.5, Q7.6, Q7.7, Q7.8, Q7.9
unnamed: LED1.1, R38.2
unnamed: LED2.1, R39.2
unnamed: LED2.2, Q8.3
unnamed: Q1.4, R5.2, R9.1
unnamed: Q2.4, R7.1, R8.1
unnamed: Q3.4, R15.2, R19.1
unnamed: Q4.4, R17.1, R18.1
unnamed: Q5.4, R24.2, R27.1
unnamed: Q6.4, R25.1, R26.1
unnamed: Q7.4, R35.1
unnamed: Q8.1, R40.2
unnamed: C4.1, U1.20 (BSTA)
unnamed: C7.1, U1.17 (BSTB)
unnamed: C9.1, U1.14 (BSTC)
unnamed: R5.1, U1.19 (GHA)
unnamed: R15.1, U1.16 (GHB)
unnamed: R24.1, U1.13 (GHC)
unnamed: R7.2, U1.11 (GLA)
unnamed: R17.2, U1.10 (GLB)
unnamed: R25.2, U1.9 (GLC)
unnamed: Q2.1, Q2.2, Q2.3, R8.2, R12.1, U2.3 (IN+)
unnamed: R1.2, U2.1 (OUT)
unnamed: Q4.1, Q4.2, Q4.3, R18.2, R20.1, U3.3 (IN+)
unnamed: R6.2, U3.1 (OUT)
unnamed: Q6.1, Q6.2, Q6.3, R26.2, R28.1, U4.3 (IN+)
unnamed: R16.2, U4.1 (OUT)
unnamed: C15.1, U5.6 (BOOT)
unnamed: C20.1, R30.2, R31.1, U5.4 (FB)
unnamed: C15.2, L1.1, U5.2 (SW)
unnamed: R33.1, U6.60 (BOOT0)
unnamed: C28.2, SW1.2, U6.7 (NRST)
unnamed: C25.1, U6.5 (PH0-OSC_IN(PH0)), X1.1
unnamed: R32.1, U6.6 (PH1-OSC_OUT(PH1))
unnamed: C24.2, U6.31 (VCAP_1)
unnamed: C22.2, U6.47 (VCAP_2)
unnamed: C21.2, C23.2, FB1.1, U6.13 (VDDA)
unnamed: R36.2, R37.2, U7.5 (ADJ)

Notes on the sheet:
Gate Driver's LDO
6 Step Configuration Proccess
Back EMF Voltage Dvider Circuit and Virtual Neutral-ADC Connection
LDO Out's and Gate Driver's Decoumpling Capacitors
STM32F405RGT6 Power Pin's Connection
Phase's Decoumpling Capacitors and Phase Power Connections.
Socket Wiring Diagram and Reverse Connection Protection.
3s to 3.3 Stable DC-DC Stepdown Regulator
STM32F405RGT6

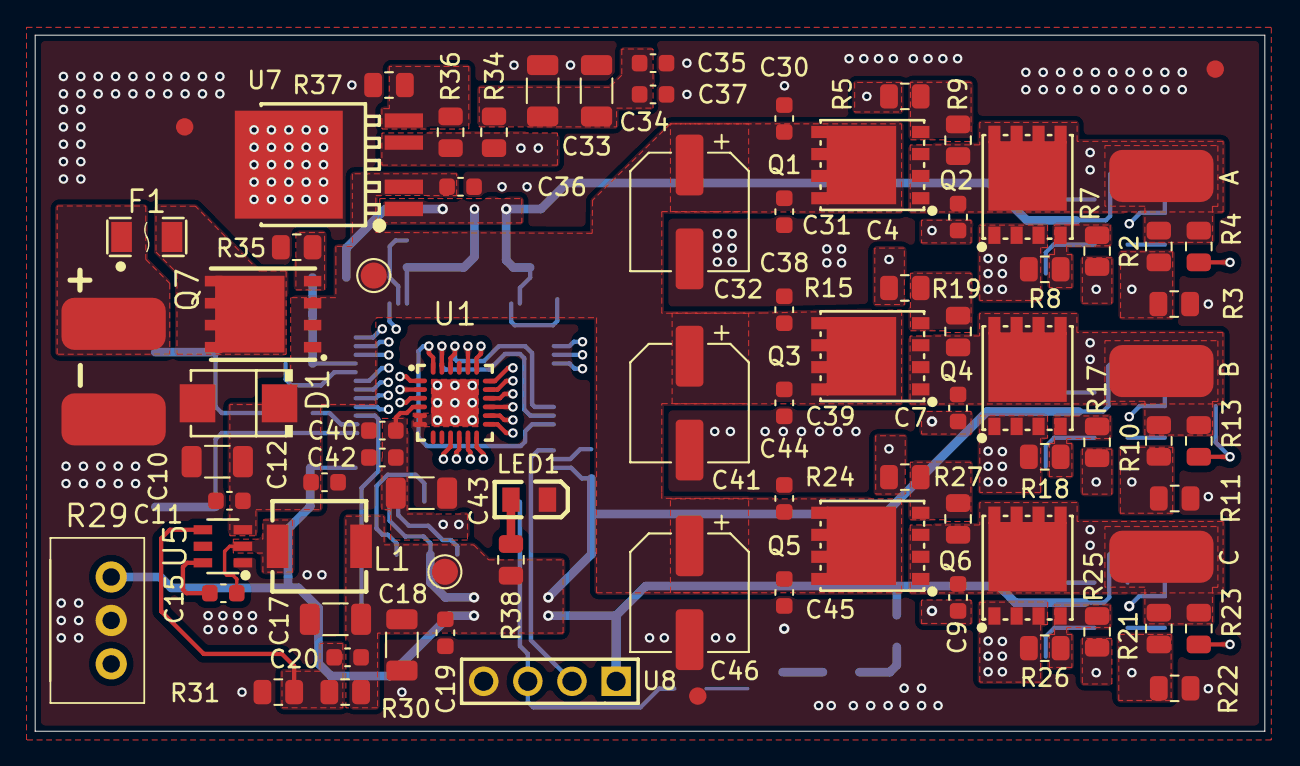
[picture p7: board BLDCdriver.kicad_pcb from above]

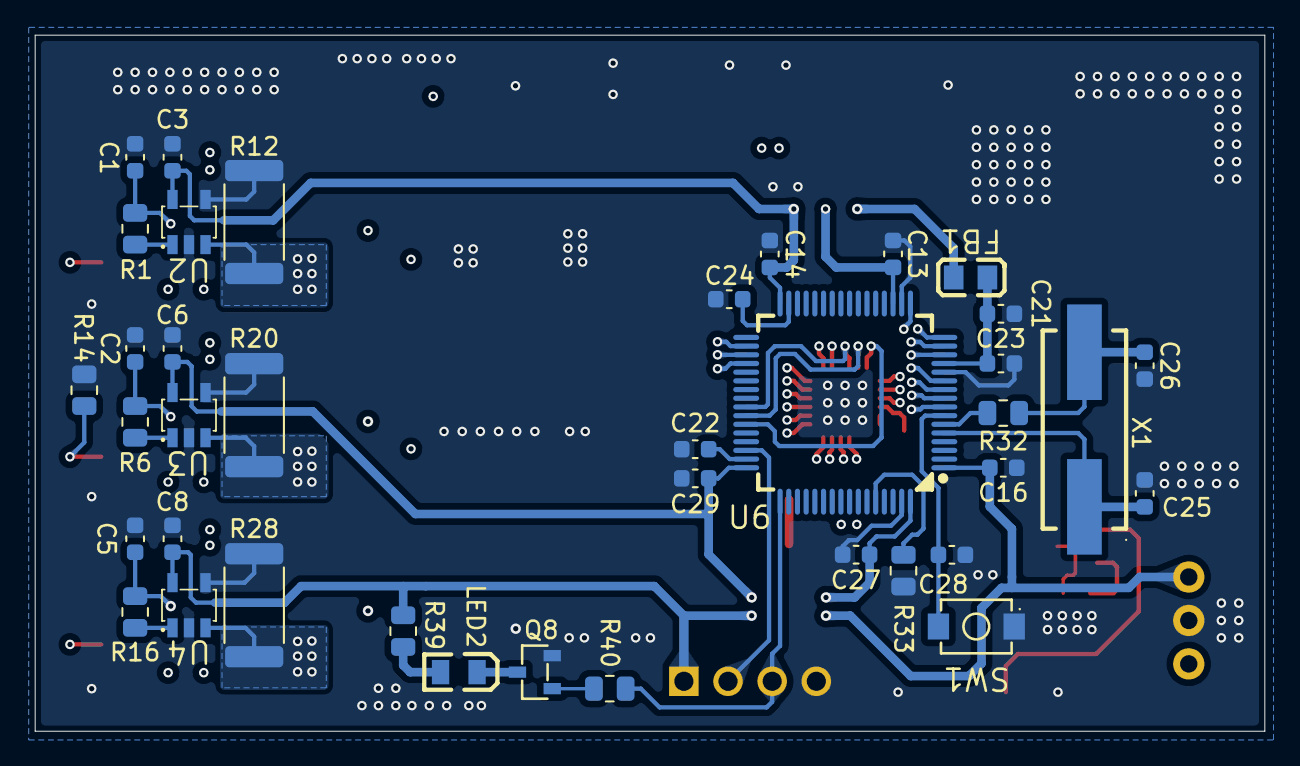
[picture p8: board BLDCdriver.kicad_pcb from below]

Board: 6 copper layers, 70.8 x 40.0 mm, 115 parts (38 on the bottom side), 64 nets.
